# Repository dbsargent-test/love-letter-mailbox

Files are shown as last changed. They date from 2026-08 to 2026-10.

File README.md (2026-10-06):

# 📬 Love Letter Mailbox — DIY WiFi Messenger

A palm-sized, WiFi-connected mailbox that displays text messages and photos on a color screen. When a message arrives, a red flag rises and a chime plays. Inspired by [Love Letter Tech](https://lovelettertech.com), built from scratch with off-the-shelf components.

**Send a message from any phone → it appears on the mailbox. No app install required.**

Architecture Overview

---

## ✨ Current V1 Features

- 📱 **Send messages from any browser** — no app to install, works on any phone/tablet/computer
- 📸 **Photo support** — send photos that render on the V1 2.0" color IPS display
- 🚩 **Physical flag** — servo raises a red flag when a new message arrives
- 🔔 **Notification chime** — Qwiic buzzer plays a tone on message arrival
- 🌙 **Auto-dimming** — ambient light sensor dims the display at night
- 🔘 **Physical button** — mark messages as read, scroll through message history
- 💗 **Read heart receipts** — sent messages show when the recipient has read them
- 🔄 **Over-the-air updates** — push firmware updates remotely, no physical access needed
- 🔋 **Battery backup** — LiPo battery keeps the device running through power blips
- 📡 **Dual-band WiFi 6** — works on 2.4GHz AND 5GHz networks (no band-steering headaches)
- ☁️ **Azure-hosted backend** — reliable, free-tier, Microsoft infrastructure
- 🔒 **Encrypted** — all communication over HTTPS

## ✨ Planned V2 Features

V2 keeps the same Azure/web/ESP32 foundation and upgrades the physical mailbox:

- 🖼️ **Larger portrait display** — Adafruit 2.8" TFT with capacitive touch, EYESPI, and microSD
- 💾 **SD-backed media cache** — downloaded pictures and audio live on the TFT microSD card, not ESP32 flash
- 🎵 **Real audio playback** — ESP32-managed audio over I2S to a MAX98357A amplifier and enclosed speaker
- 💗 **Translucent glowing heart** — 3D-printed translucent heart insert lit by a NeoPixel Jewel
- 👆 **Heart-back touch input** — copper foil electrode and MPR121 capacitive touch sensing
- 💓 **Haptic heartbeat** — DRV2605L haptic controller and vibration motor
- 🧲 **Flag-state sensing** — Hall-effect sensor and magnet/reed-switch fallback
- 🔋 **Larger battery** — 2200mAh cylindrical LiIon cell, requiring a redesigned tray
- 🧰 **Serviceable internal layout** — new floor/tray for ESP32 bottom headers, microSD access, speaker chamber, haptics, and wiring

Full V2 planning is tracked in [docs/v2-build-plan.md](docs/v2-build-plan.md).

---

## 💰 V1 Cost Comparison

| | Love Letter Tech (Commercial) | This Project (DIY) |
|---|---|---|
| **Price** | $129 | **~$92** |
| **Dual-band WiFi** | ❌ (2.4GHz only) | ✅ WiFi 6 dual-band |
| **Battery backup** | ❌ | ✅ 850mAh LiPo |
| **Auto-dimming** | ❌ | ✅ Ambient light sensor |
| **Notification sound** | ❌ | ✅ Qwiic buzzer |
| **Physical button** | ❌ | ✅ Read/scroll |
| **OTA updates** | Unknown | ✅ Remote firmware updates |
| **Open source** | ❌ | ✅ Fully open |
| **Requires app install** | ✅ iOS/Android app | ❌ Any browser works |

---

## 💰 V2 Cost / Capability Snapshot

V2 is no longer optimized only for lowest cost; it is optimized for richer
interaction and OTA-manageable media.

| Area | V1 | V2 plan |
|---|---|---|
| Display | 2.0" ST7789 | 2.8" Adafruit #2090 TFT with capacitive touch and microSD |
| Notification sound | Qwiic buzzer tones | WAV/audio files from microSD through MAX98357A + speaker |
| Heart interaction | Read-heart receipt in web/app flow | Physical glowing/touch/haptic heart |
| Media storage | ESP32 RAM/cache + backend blobs | ESP32-managed microSD cache for downloaded images/audio |
| Battery | 850mAh flat LiPo | 2200mAh cylindrical LiIon |
| Enclosure | V1 tray and display fit | New tray required for bottom headers, battery, heart, speaker, and SD access |
| Incremental V2 purchases | — | Adafruit electronics order + Amazon microSD cards placed |

---

## 🛒 V1 Bill of Materials

| Part | Source | Product | Price |
|---|---|---|---|
| ESP32-C5 Thing Plus (×2) | SparkFun | [Thing Plus ESP32-C5](https://www.sparkfun.com/sparkfun-thing-plus-esp32-c5.html) | $24.95 ea |
| 2.0" TFT Display (2-pack) | Amazon | [XIITIA 2.0" ST7789 240×320 IPS](https://www.amazon.com/dp/B0DFWLD38D) | ~$12 |
| LiPo Battery 850mAh | SparkFun | [Lithium Ion Battery 850mAh](https://www.sparkfun.com/lithium-ion-battery-850mah.html) | $13.61 |
| Ambient Light Sensor | SparkFun | [VEML6030 Qwiic](https://www.sparkfun.com/sparkfun-ambient-light-sensor-veml6030-qwiic.html) | ~$6 |
| Buzzer | SparkFun | [Qwiic Buzzer](https://www.sparkfun.com/sparkfun-qwiic-buzzer.html) | ~$7 |
| Button | SparkFun | [Qwiic Button Red LED](https://www.sparkfun.com/products/15932) | ~$5 |
| Qwiic Cables 200mm (×3) | SparkFun | [Flexible Qwiic Cable 200mm](https://www.sparkfun.com/flexible-qwiic-cable-200mm.html) | $1.95 ea |
| SG90 Micro Servo | On hand | — | $0 |
| 3D Printed Enclosure | Self | STL files in `/enclosure` | ~$1 |
| **Total** | | | **~$92** |

> **Note:** BOM builds TWO complete mailboxes (one for you, one for recipient). Per-unit cost is ~$46.
> V2 uses a different expansion BOM; see [docs/v2-build-plan.md](docs/v2-build-plan.md).

---

## 🛒 V2 Bill of Materials

### Reused / Already In Stock

| Part | Purpose |
|---|---|
| SparkFun Thing Plus ESP32-C5 | Main controller, Wi-Fi, OTA, Qwiic, LiPo charging |
| 18-pin EYESPI FPC cable | Display cabling |
| EYESPI breakout / host wiring path | Prototyping and signal breakout |
| SparkFun Qwiic Button with LED | Fallback / alternate physical control |
| SparkFun VEML6030 ambient light sensor | Auto-dim / ambient light input |
| SG90 micro servo | Mailbox flag actuation |
| Qwiic cables | I2C daisy-chain wiring |

### Ordered for V2

| Part | Source / ID | Purpose |
|---|---|---|
| 2.8" TFT LCD with capacitive touch, EYESPI, and microSD | Adafruit #2090 | Larger display and media storage |
| MAX98357A I2S 3W Class-D mono amplifier | Adafruit #3006 | ESP32-managed audio playback |
| Mono enclosed speaker, 3W 4Ω | Adafruit #3351 | Audio output |
| DRV5032 digital magnetic Hall-effect sensor | Adafruit / ScoutMakes #6051 | Flag position sensing |
| Magnetic contact switch | Adafruit #375 | Magnet source / fallback contact sensor |
| 2200mAh cylindrical LiIon battery | Adafruit #1781 | Larger V2 power reserve |
| NeoPixel Jewel | Adafruit #2226 | Translucent heart glow |
| MPR121 capacitive touch sensor | Adafruit #4830 | Heart touch / heart-back input |
| Copper foil tape | Adafruit #1127 | Touch electrode |
| DRV2605L haptic motor controller | Adafruit #2305 | Heartbeat vibration effects |
| Vibrating mini motor disc | Adafruit #1201 | Haptic output |
| Half-size breadboard + jumper bundle | Adafruit #3314 | ESP32 fanout and shared power/ground rows |
| Lexar E-Series 32GB microSDHC UHS-I cards, 3-pack | Amazon | Media cache for downloaded pictures and audio |

### V2 Items Still Pending

| Item | Depends on |
|---|---|
| Speaker gasket, grille, and acoustic chamber | Final speaker location and vent geometry |
| M2/M2.5 screws, heat-set inserts, or self-tapping screws | Final display, speaker, sensor, and tray mounts |
| Optional separate microSD breakout | Only if the #2090 TFT microSD slot is not serviceable |

---

## 🏗️ V1 System Architecture

```
┌─────────────────────┐         ┌──────────────────────┐
│   Any Phone/Browser │         │    Azure Cloud       │
│                     │         │                      │
│  ┌───────────────┐  │  HTTPS  │  ┌────────────────┐  │
│  │ Messaging     │──┼────────►│  │ Static Web App │  │
│  │ Web Page      │  │         │  │ + Azure Func.  │  │
│  └───────────────┘  │         │  └───────┬────────┘  │
└─────────────────────┘         │          │           │
                                │  ┌───────▼────────┐  │
                                │  │ Table Storage   │  │
                                │  │ (messages)      │  │
                                │  └───────┬────────┘  │
                                │          │           │
                                │  ┌───────▼────────┐  │
                                │  │ Blob Storage    │  │
                                │  │ (photos + OTA)  │  │
                                │  └────────────────┘  │
                                └──────────┬───────────┘
                                           │ HTTPS poll
                                           │ every 5s
                                ┌──────────▼───────────┐
                                │   ESP32-C5 Mailbox   │
                                │                      │
                                │  ┌────────────────┐  │
                                │  │ V1 2.0" TFT    │  │
                                │  │ (text + photos)│  │
                                │  ├────────────────┤  │
                                │  │ Servo (flag)   │  │
                                │  ├────────────────┤  │
                                │  │ Buzzer (chime) │  │
                                │  ├────────────────┤  │
                                │  │ Light sensor   │  │
                                │  │ (auto-dim)     │  │
                                │  ├────────────────┤  │
                                │  │ Button (read/  │  │
                                │  │ scroll)        │  │
                                │  ├────────────────┤  │
                                │  │ LiPo (backup)  │  │
                                │  └────────────────┘  │
                                └──────────────────────┘
```

---

## 🏗️ V2 Device Architecture

The cloud/backend remains the same. The physical device changes from a buzzer
and 2.0" display into an ESP32-managed media and interaction hub:

```
Azure Static Web App + Functions + Table/Blob Storage
        │
        │ HTTPS: messages, photos, firmware, media metadata
        ▼
SparkFun Thing Plus ESP32-C5
        │
        ├── SPI / EYESPI ── Adafruit #2090 2.8" TFT
        │                    └── microSD media cache
        │
        ├── I2S ─────────── MAX98357A amp ── enclosed speaker
        │
        ├── GPIO ────────── NeoPixel Jewel behind translucent heart
        │
        ├── I2C/Qwiic ───── VEML6030 light sensor
        │              ├── MPR121 capacitive touch sensor
        │              └── DRV2605L haptic controller ── vibration motor
        │
        ├── GPIO ────────── Hall sensor / magnetic contact path
        │
        ├── PWM ─────────── SG90 flag servo
        │
        └── Battery ─────── 2200mAh cylindrical LiIon
```

The V2 firmware must add microSD file management, audio playback, NeoPixel
effects, capacitive touch, haptic effects, and flag-state sensing before the
new enclosure is treated as final.

---

## 🚀 Quickstart

### V1: Build / Run the Current Device

#### 1. Deploy the Azure Backend
See [docs/azure-setup.md](docs/azure-setup.md) for step-by-step instructions.

#### 2. Flash the Firmware
See [docs/firmware-setup.md](docs/firmware-setup.md) for Arduino IDE setup and flashing.

#### 3. Wire the Hardware
See [docs/wiring.md](docs/wiring.md) for pin connections and Qwiic daisy-chain.

#### 4. Print the Enclosure
STL files in [`/enclosure`](enclosure/). Any FDM printer works.

#### 5. Connect and Send Messages
Open the messaging web page, type a message, hit send. Watch the flag rise. ❤️

### V2: Build Path

V2 is in hardware planning/prototyping, not a ready-to-print release. The next
steps are:

1. Validate the #2090 TFT and microSD from the ESP32-C5.
2. Validate SD-backed image and audio file read/write.
3. Validate MAX98357A I2S audio playback from microSD.
4. Validate NeoPixel glow through translucent print samples.
5. Validate MPR121 touch detection through the heart/copper stack.
6. Validate DRV2605L haptics and motor placement.
7. Validate Hall sensor and magnet alignment for flag position.
8. Redesign the floor/tray around bottom-header ESP32 clearance and #1781 battery placement.
9. Print a fit coupon before printing a full V2 enclosure.

---

## 📖 Documentation

| Guide | Description |
|---|---|
| [Architecture](docs/architecture.md) | System design, failure analysis, and design decisions |
| [Bill of Materials](docs/bom.md) | Complete parts list with purchase links |
| [V2 Build Plan](docs/v2-build-plan.md) | V2 hardware architecture, ordered BOM, media storage, and enclosure implications |
| [Wiring Guide](docs/wiring.md) | Pin connections + Qwiic daisy-chain diagram |
| [Azure Setup](docs/azure-setup.md) | Deploy the backend in 15 minutes |
| [Firmware Setup](docs/firmware-setup.md) | Arduino IDE configuration + flashing |
| [OTA Updates](docs/ota-updates.md) | Push firmware updates remotely |
| [Troubleshooting](docs/troubleshooting.md) | Common issues and fixes |
| [Project Journal](docs/project-journal.md) | Build log, scope tracker, budget, and session history |

---

## 🛡️ Design Philosophy

This project was designed with **failure resistance** as the top priority. Every component choice was made to minimize the chance of the device becoming a paperweight:

- **Dual-band WiFi 6** eliminates the #1 ESP32 failure mode (2.4GHz band-steering hell)
- **Simple HTTP polling** instead of persistent connections — nothing to disconnect
- **Azure Table Storage** — Microsoft's oldest, most durable storage service
- **No native app** — a static web page can't break from app store policy changes
- **OTA updates** — fix bugs remotely without physical access
- **Battery backup** — survives power blips without losing state
- **Watchdog timer** — auto-reboots if firmware hangs

See [docs/architecture.md](docs/architecture.md) for the full failure analysis and design rationale.

---

## 📜 License

MIT License — build one, sell one, modify it, do whatever you want.

---

## 📊 Project Health

| Metric | Value |
|---|---|
| Current firmware source | **v1.2.10** |
| V1 physical build | **Complete / validated** |
| V2 hardware planning | **Captured; parts ordered; firmware/CAD not yet implemented** |
| Original features replicated | 8 of 10 (80%) |
| V1 features added beyond original | 9 |
| V1 scope creep ratio | 0.9x |
| V1 cost vs commercial ($129) | **$57/unit (56% cheaper)** |
| V2 primary blocker | **Validate new hardware stack before redesigning enclosure** |
| Monthly hosting cost | ~$0.02 |
| Architecture failure resistance score | **9.7 / 10** |

See [Project Journal](docs/project-journal.md) for full scope creep analysis and build log.

---

## 🌐 Live Backend

| Resource | URL |
|---|-----|
| Messaging Web App | https://zealous-dune-001e8941e.7.azurestaticapps.net |
| Azure Resource Group | `love-letter-mailbox` (West US 2) |

---

## 🙏 Acknowledgments

Inspired by [Love Letter Tech](https://lovelettertech.com) by Owen O'Brien. This is an independent open-source reimplementation — not affiliated with Love Letter Tech.

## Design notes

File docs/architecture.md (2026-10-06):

# Architecture & Design Decisions

## Lessons Learned

### 2026-09-17 — Use the policy-compatible ESP32-C5 toolchain helper

Windows Application Control blocks the temporary Python DLL extracted by
Espressif's bundled PyInstaller tools. Repeated Arduino CLI upload overrides
still invoked the blocked executable and failed before writing flash.

Use `scripts\esp32c5-toolchain.ps1` for both operations. Compilation routes the
partition generator through the installed Python runtime; upload consumes the
generated `flash_args` with `python -m esptool`. Do not weaken Application
Control or rediscover command-line overrides in later sessions.

### 2026-09-17 — SPI animations must not clear the full display per frame

The first floating-hearts screensaver cleared and redrew the entire 320×240
ST7789 every 120 ms. Because the display has no frame buffer or vertical-sync
swap, the cleared frame became visible over SPI and made the screen blink.

Animated elements now move in side lanes around a static central panel. Each
frame erases only the previous heart bounds and draws the new positions.
`tests\regression\test-landscape-screensaver-prefetch.ps1` rejects any return
of `display.fillScreen()` to the animated frame renderer.

### 2026-09-17 — Session revocation must be global and fail closed

Password changes previously revoked only the token used for the request, while
password resets revoked no active sessions. Revocation-table errors were also
treated as "not revoked," allowing stolen seven-day JWTs to survive account
recovery or a storage outage.

Every user now has a monotonic `sessionVersion` included in JWTs and checked
against Table Storage on every protected request. Password changes and resets
increment the version, invalidating all older sessions. Revocation lookup
returns "not revoked" only for an explicit entity-not-found response; other
storage failures return an authentication-service error rather than accepting
the token. Device credentials are accepted only through `x-device-key`, never
through query strings.

### 2026-09-16 — Native image dependencies must match the SWA runtime

The first image-normalization deployment returned HTTP 500 from the messages
function because Windows SWA CLI packaged only Sharp's Windows ARM64 native
binary, while Azure Static Web Apps runs Linux x64. The API source and package
lock were correct, which made the failure invisible to local tests.

Before every Windows-originated SWA deployment, run `npm --prefix web\api run
prepare:swa` to add Sharp and libvips for Linux x64 to the local deployment
tree. `tests\regression\test-swa-sharp-runtime.ps1` prevents removal of that
deployment gate.

### 2026-09-16 — Qwiic queue values are elapsed ages, not timestamps

The Qwiic Button maintains separate press and click queues. Their values are
milliseconds elapsed since each event, and unmatched press entries can remain
in the device queue. Pairing the oldest values without resynchronization caused
a quick tap to be measured as a 270,584 ms hold.

The firmware now discards implausible unmatched entries, computes hold duration
from paired ages, reconstructs the click time as `millis() - clickAge`, and
logs the selected action. The double-click window is 750 ms because USB traces
showed a normal double press at 707 ms. The regression guard is
`tests\regression\test-button-gesture-timing.ps1`.

## Overview

The Love Letter Mailbox is a WiFi-connected IoT device that receives text
messages and photos from a web interface and displays them on a color TFT
screen. The validated V1 hardware raises a servo-driven flag when a new message
arrives, plays a Qwiic buzzer notification chime, and uses a physical button to
mark messages as read. V2 planning is tracked in
[Mailbox V2 Build Plan](v2-build-plan.md) and adds a larger TFT, SD-backed media
cache, real audio playback, translucent glowing heart, capacitive heart-back
input, haptic feedback, and flag-state sensing.

## Design Principles

1. **Minimize failure modes** — every architectural choice prioritizes reliability over cleverness
2. **No persistent connections** — HTTP polling over MQTT/WebSockets to eliminate connection state management
3. **No native app** — a static web page works on any device without installation or app store approval
4. **Normalize once in the backend** — browser previews are optimized, but the
   API authoritatively rotates and scales every stored photo
5. **Vendor-portable** — the ESP32 code is just "fetch JSON from a URL"; swap backends by changing one URL

---

## Component Selection Rationale

### ESP32-C5 (over classic ESP32)

| Factor | ESP32 (classic) | ESP32-C5 |
|---|---|---|
| WiFi | 2.4GHz only | **Dual-band 2.4 + 5GHz WiFi 6** |
| RAM | 520KB SRAM | 384KB SRAM + **8MB PSRAM** |
| Flash | 4MB | **8MB** |
| Battery | External charging circuit needed | **Built-in LiPo charger + fuel gauge** |
| Power safety | Brownout-prone on WiFi TX | LiPo battery acts as capacitor |

**Decision:** The ESP32-C5 eliminates the two most common IoT project failures:
1. **2.4GHz WiFi incompatibility** with modern routers that use band steering
2. **Memory crashes** when decoding photos (8MB PSRAM vs 520KB SRAM)

The $19 premium ($25 vs $6) is justified by the elimination of these failure modes.

### Azure Static Web App + Table Storage (over Firebase, MQTT, Blynk)

Three architectures were evaluated:

#### Option A: Firebase Realtime DB + PWA
- **Pros:** Well-documented, free tier generous, real-time listeners
- **Cons:** Google dependency, Firebase SDK on ESP32 is heavy, vendor lock-in
- **Score:** 8.0/10

#### Option B: MQTT (HiveMQ) + Telegram Bot
- **Pros:** MQTT is resilient by design, Telegram is battle-tested
- **Cons:** Needs bridge server between Telegram and MQTT (single point of failure), more moving parts
- **Score:** 8.0/10

#### Option C: Azure Static Web App + Table Storage ✅ SELECTED
- **Pros:** Fewest moving parts, ESP32 just does HTTP GET, Table Storage is nearly indestructible (99.999999999% durability), $0.01/mo cost, no SDK needed
- **Cons:** Polling instead of push (5-second delay is acceptable for a mailbox)
- **Score:** 9.7/10

**Decision:** Option C wins on simplicity, cost, and failure resistance. The ESP32 code is just `HTTPClient.GET()` — no MQTT library, no Firebase SDK, no connection state to manage. If Azure ever changes, swapping to any JSON endpoint takes ~10 lines of code change.

### V1 2.0" ST7789 TFT (over 1.3", 1.69", 2.4")

| Display | Resolution | Photo Quality | Enclosure Fit |
|---|---|---|---|
| 1.3" | 240×240 | Too small for photos | Very compact |
| 1.69" | 240×280 | Recognizable but tight | Compact |
| **2.0"** | **240×320** | **Good — natural photo aspect ratio** | **Palm-sized mailbox** |
| 2.4" | 240×320 | Good | Enclosure gets bulky |

**V1 decision:** 2.0" was the validated V1 sweet spot. 240×320 matches standard
photo aspect ratios, avoiding letterboxing. Physically only ~5mm larger than
1.69" but noticeably better for photo viewing.

**V2 update:** V2 moves to Adafruit #2090, a 2.8" TFT with capacitive touch,
EYESPI, and microSD. The larger display and SD socket drive the V2 enclosure,
media-cache, and power-budget work in [v2-build-plan.md](v2-build-plan.md).

---

## Failure Analysis

### Risk Register

| # | Failure Mode | Pre-Mitigation Risk | Mitigation | Post-Mitigation Risk |
|---|---|---|---|---|
| 1 | 2.4GHz WiFi band-steering | HIGH | ESP32-C5 dual-band WiFi 6 | **ELIMINATED** |
| 2 | Cloud service changes/dies | MEDIUM | Azure Table Storage (oldest Azure service), no SDK lock-in, swap backend in 10 lines | **LOW** |
| 3 | WiFi reconnect failures | HIGH | WiFi 6 better connection management + hardware watchdog + exponential backoff | **LOW** |
| 4 | Power brownouts | MEDIUM | LiPo battery acts as UPS during voltage dips | **ELIMINATED** |
| 5 | TLS cert expiration | LOW | Azure-managed certs, Arduino core updates CA bundle | **VERY LOW** |
| 6 | Photo decode OOM crash | MEDIUM | 8MB PSRAM for decode buffer; fallback: pre-convert to RGB565 in browser | **ELIMINATED** |
| 7 | Web UI/app maintenance | MEDIUM | Static HTML/JS, no framework dependencies, no native app | **LOW** |
| 8 | WiFi provisioning confusion | HIGH | Captive portal + dual-band means no "split your SSID" instructions needed | **LOW** |

### Resilience Features

- **Hardware watchdog:** Auto-reboots ESP32 after 60 seconds of unresponsiveness
- **Exponential backoff:** WiFi reconnect attempts with increasing delays (1s, 2s, 4s, 8s... max 60s)
- **Dual OTA partitions:** Failed firmware update auto-rolls back to previous working version
- **Message persistence:** Azure Table Storage holds last 20 messages; ESP32 fetches unread on boot
- **Offline display:** Last message stays on screen even if WiFi drops
- **Battery fuel gauge:** Firmware can warn when battery is low (display icon)

---

## Data Flow

### Sending a Message

```
1. User opens web page on phone/computer
2. Types message and/or attaches photo
3. Browser creates an aspect-ratio-preserving preview within 216×160
4. JavaScript POSTs to Azure Function: POST /api/messages
5. Azure Function rotates the photo from metadata, strips metadata, converts it
   to baseline JPEG, and fits it inside 216×160 without cropping, stretching,
   enlarging, or changing portrait/landscape orientation
6. Azure Function writes to Table Storage:
   - PartitionKey: device ID
   - RowKey: timestamp
   - Text: message content
   - PhotoUrl: Blob Storage URL (if photo)
   - Read: false
7. Function returns 200 OK
```

### Receiving a Message

```
1. ESP32-C5 polls GET /api/messages?unread=true every 5 seconds
2. If unread messages exist:
   a. Raise servo flag
   b. V1: play Qwiic buzzer chime; V2: play SD-backed audio through I2S amp
   c. Display message text on TFT
   d. If photo: use one of two RAM cache slots or download from Blob Storage,
      decode, center, and render without changing its aspect ratio
3. When button pressed:
   a. Mark message as read: PATCH /api/messages/{id}
   b. Lower servo flag
   c. Show next unread message (if any) or return to idle screen
```

### OTA Firmware Update

```
1. On boot + every 15 minutes: GET /api/device/firmware
2. Compare server version string to local version
3. If server > local:
   a. Download .bin from Azure Blob Storage
   b. Write to OTA partition B
   c. Verify checksum
   d. Set boot partition to B
   e. Reboot
4. The new image is confirmed only after display and I2C peripherals initialize
5. If the pending image reboots before confirmation, the ESP32 bootloader can
   return to the previous OTA partition
```

---

## V1 Qwiic Daisy-Chain

V1 I2C peripherals connect via the Qwiic connector system — no soldering required:

```
ESP32-C5 Qwiic Port
    │
    ├── [200mm cable] ── VEML6030 Light Sensor
    │                         │
    │                    [200mm cable]
    │                         │
    │                    Qwiic Buzzer
    │                         │
    │                    [200mm cable]
    │                         │
    │                    Qwiic Button
    │
    └── [SPI wires] ── 2.0" ST7789 TFT Display
    │
    └── [signal wire] ── SG90 Servo
```

### I2C Addresses (no conflicts)
| Device | Address |
|---|---|
| VEML6030 | 0x48 |
| Qwiic Buzzer (ATtiny84) | 0x34 |
| Qwiic Button | 0x6F |
| MAX17048 Fuel Gauge (onboard) | 0x36 |

V2 adds MPR121 capacitive touch and DRV2605L haptic control on I2C. Their
addresses must be scanned before final wiring; if both use the same default
address, change the MPR121 address before integrating both boards.

---

## Azure Resource Summary

| Resource | Tier | Monthly Cost | Purpose |
|---|---|---|---|
| Static Web App | Free | $0 | Hosts messaging web page + API functions |
| Storage Account (Table) | Standard | ~$0.01 | Message storage |
| Storage Account (Blob) | Standard | ~$0.01 | Photo storage + OTA firmware binaries |
| **Total** | | **~$0.02/mo** | |

All resources fit within the Azure free tier and/or the $200/mo Visual Studio Enterprise credit.

---

## Future Enhancements

- [x] Read receipts (sender sees when message was viewed)
- [ ] V2 SD-backed audio playback (MAX98357A + speaker)
- [ ] V2 heart-back interaction (capacitive touch + haptics)
- [ ] Emoji rendering (custom font with emoji glyphs)
- [ ] Weather display on idle screen
- [ ] Multiple device pairing (family group messaging)
- [ ] E-ink display option for ultra-low power
- [ ] Custom notification melodies
- [ ] Message reactions / heart-back replies

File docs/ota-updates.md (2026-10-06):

# OTA (Over-the-Air) Firmware Updates

## Overview

The mailbox firmware includes built-in OTA update capability. Once the initial firmware is flashed via USB, all subsequent updates can be pushed remotely — no physical access to the device required.

This is critical for a device deployed at someone else's house.

This page covers firmware OTA. V2 also needs an OTA media-cache workflow for
downloaded pictures and audio files stored on the #2090 TFT microSD card; that
media workflow is planned separately in [Mailbox V2 Build Plan](v2-build-plan.md).

---

## How It Works

```
1. You compile new firmware → export as .bin
2. Upload .bin to Azure Blob Storage
3. Update version number in Azure Table Storage
4. ESP32-C5 checks for updates on boot + every 15 minutes
5. If new version available → downloads .bin → installs → reboots
6. If new firmware crashes → auto-rollback to previous version
```

---

## Architecture

### ESP32-C5 Flash Partition Layout

The ESP32-C5 has 8MB flash, partitioned as:

| Partition | Size | Purpose |
|---|---|---|
| bootloader | 32KB | First-stage bootloader |
| partition table | 4KB | Partition layout |
| nvs | 20KB | WiFi credentials + settings |
| ota_0 | ~3.5MB | Firmware slot A (active) |
| ota_1 | ~3.5MB | Firmware slot B (OTA target) |
| ota_data | 8KB | Tracks which slot is active |
| spiffs/littlefs | ~512KB | Fonts, splash screens, cached data |

### Update Flow

```
Current firmware running from ota_0
    │
    ├── GET /api/device/firmware
    │   Response: { "version": "1.2.5", "url": "https://...blob.../firmware-1.2.5.bin" }
    │
    ├── Compare: local "1.2.4" < server "1.2.5" → update needed
    │
    ├── Download firmware-1.2.5.bin to ota_1 partition
    │
    ├── Verify checksum (SHA-256)
    │
    ├── Set ota_data to boot from ota_1
    │
    └── Reboot
        │
        ├── New firmware boots from ota_1
        │   ├── Initializes the display and required I2C peripherals
        │   ├── If initialization passes → mark ota_1 as confirmed
        │   └── If it reboots before confirmation → bootloader can roll back
        │
        └── Device now running v1.2.5
```

---

## Step-by-Step: Pushing an Update

### 1. Compile New Firmware

Use the policy-compatible repository helper from the repo root. The OTA build
must use the Minimal SPIFFS partition and should redact local source paths from
the binary:

```powershell
$build = "C:\Temp\mailbox-firmware-build-vNEXT"
$map = "-ffile-prefix-map=C:\Users\dosarge=."
$props = @(
  "compiler.c.extra_flags=$map",
  "compiler.cpp.extra_flags=$map",
  "compiler.S.extra_flags=$map"
)

.\scripts\esp32c5-toolchain.ps1 `
  -Action Compile `
  -SketchDirectory .\firmware\mailbox_firmware `
  -BuildPath $build `
  -Fqbn "esp32:esp32:sparkfun_esp32c5_thing_plus:PartitionScheme=min_spiffs" `
  -ExtraBuildProperty $props
```

The OTA application binary is:

```text
$build\mailbox_firmware.ino.bin
```

Do **not** upload the merged 8 MB image for OTA.

### 2. Upload to Azure Blob Storage

```bash
# Using Azure CLI
az storage blob upload \
  --account-name <your-storage-account> \
  --container-name firmware \
  --name firmware-<version>.bin \
  --file <build-path>/mailbox_firmware.ino.bin \
  --overwrite
```

Or upload via the Azure Portal: Storage Account → Containers → firmware → Upload.

### 3. Update Version Metadata

The device endpoint is controlled by Static Web App app settings, not by a
firmware metadata table. The critical hash is the **ESP image validation hash**,
not the raw file SHA-256.

Get the correct validation hash with:

```powershell
python -m esptool image-info "<build-path>\mailbox_firmware.ino.bin"
```

Use the `Validation hash: ... (valid)` value from the output. Do **not** use
`Get-FileHash` for `FIRMWARE_SHA256`; the firmware verifies OTA with
`esp_partition_get_sha256(updatePartition)`, which matches the ESP image
validation hash, not the raw `.bin` file hash.

Update the Static Web App metadata:

```powershell
az staticwebapp appsettings set `
  --name love-letter-app `
  --resource-group love-letter-mailbox `
  --setting-names `
    FIRMWARE_RELEASE_ENABLED=true `
    FIRMWARE_VERSION=<version> `
    FIRMWARE_BLOB_NAME=firmware-<version>.bin `
    FIRMWARE_SHA256=<ESP image validation hash> `
    FIRMWARE_RELEASE_NOTES="<short release note>"
```

### 4. Wait

The ESP32 checks for updates:
- On every boot
- Every 15 minutes while running in normal release builds
- Every 2 minutes in temporary test builds such as v1.2.7+

Within 15 minutes, the device will check for an update. Reboot the device to
trigger an earlier check after Wi-Fi reconnects.

---

## Safety Features

### Automatic Rollback
The firmware confirms a pending OTA image only after the display and required
I2C peripherals initialize. If the image reboots before confirmation, the
ESP32 bootloader can return to the previous OTA partition. Wi-Fi connectivity
is retried independently and is not currently part of the confirmation gate.

### Checksum Verification
Before installing, the firmware verifies the downloaded OTA partition with
`esp_partition_get_sha256(updatePartition)` against `FIRMWARE_SHA256` from the
version metadata. That value must be the ESP image validation hash reported by
`python -m esptool image-info`, not the raw `.bin` file SHA-256. If the wrong
hash type is published, the mailbox shows `OTA verification failed` and remains
on the previous firmware version.

### Incremental Updates Only
The ESP32 only updates if the server version is **newer** than the local version. This prevents update loops and unnecessary reboots.

---

## Security Considerations

- **HTTPS only:** Firmware is downloaded over HTTPS from Azure Blob Storage
- **SAS tokens:** Use Azure Shared Access Signatures with expiration to secure the firmware blob
- **No unsigned code:** Consider adding firmware signing in v2 (verify the binary was built by you before installing)
- **Version rollback protection:** The firmware won't "downgrade" to an older version unless forced via USB

---

## Monitoring

The firmware logs OTA activity to the serial console:
```
[OTA] Checking for updates...
[OTA] Current version: 1.1.0
[OTA] Server version: 1.2.0
[OTA] Update available! Downloading...
[OTA] Download complete. Size: 1,234,567 bytes
[OTA] SHA-256 verified.
[OTA] Installing to partition ota_1...
[OTA] Install complete. Rebooting...
```

If the device is remote and you can't access serial, the firmware posts heartbeat
and OTA lifecycle telemetry to `POST /api/device/status`; the API stores the
latest snapshot in `deviceStatus` and event history in `deviceEvents`.

---

## Emergency Recovery

If OTA fails AND the rollback fails (extremely unlikely with dual partitions):

1. Physical access required
2. Connect USB-C cable
3. Hold BOOT button + press RESET to enter bootloader mode
4. Flash firmware via Arduino IDE as usual
5. This is the only scenario where physical access is needed after initial deployment

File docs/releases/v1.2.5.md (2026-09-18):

# Firmware v1.2.5

Build date: 2026-09-17

## Highlights

- Landscape 320x240 display layout.
- Floating-hearts screensaver after two minutes of inactivity.
- Photo prefetch before notification and first reveal.
- Two-slot LRU photo cache with a 512 KB per-image limit.
- Single-press next, double-press back, and one-second hold to mark read.
- Authenticated OTA polling every 15 minutes.

## Build

| Property | Value |
|---|---|
| Board | SparkFun ESP32-C5 Thing Plus |
| FQBN | `esp32:esp32:sparkfun_esp32c5_thing_plus` |
| Partition | Minimal SPIFFS (`min_spiffs`) |
| Espressif Arduino core | 3.3.11 |
| Binary size | 1,359,280 bytes |
| Program storage | 1,359,133 bytes (69%) |
| Dynamic memory | 71,564 bytes (21%) |
| SHA-256 | `613b6bc3219ce74f4dc39a4564869f9929fb80bd827f8d2fd5d3a1d003bb0e51` |

The release asset is compiled without `EMBED_PROVISIONING_SECRETS`. It contains
no Wi-Fi password, device key, deployment URL, or private build path. Existing
devices load their configuration from NVS.

## Validation

- Arduino compilation succeeded.
- ESP image type detected as ESP32-C5 with 8 MB flash.
- Image checksum and validation hash passed.
- API tests and firmware regression guards passed.

The binary has not yet been installed on the physical mailbox or validated
through an OTA upgrade from v1.2.4.

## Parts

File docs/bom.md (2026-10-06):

# V1 Bill of Materials

> **This BOM builds TWO complete mailboxes** (one for you, one for your recipient).
> Per-unit cost: ~$46
> V2 expansion parts are tracked separately in
> [Mailbox V2 Build Plan](v2-build-plan.md).

## Core Components

| Part | Qty | Source | Product | Unit Price | Total | Notes |
|---|-----|---|---|---|---|---|
| ESP32-C5 Dev Board | 2 | SparkFun | [Thing Plus ESP32-C5](https://www.sparkfun.com/sparkfun-thing-plus-esp32-c5.html) | $24.95 | $49.90 | Dual-band WiFi 6, 8MB PSRAM, 8MB Flash, built-in LiPo charger + fuel gauge |
| 2.0" TFT Display | 2 | Amazon | [XIITIA ST7789 240×320 IPS (2-pack)](https://www.amazon.com/dp/B0DFWLD38D) | $12.00 (pack) | $12.00 | ST7789 driver, SPI, 3.3V, IPS wide viewing angle |
| Micro Servo | 2 | On hand | SG90 9g Micro Servo | — | $0 | Any SG90 clone works. Raises/lowers the flag |
| LiPo Battery | 2 | SparkFun | [Lithium Ion Battery 850mAh](https://www.sparkfun.com/lithium-ion-battery-850mah.html) | $13.61 | $27.22 | JST-PH connector, plugs directly into C5 Thing Plus |

## Qwiic Peripherals

| Part | Qty | Source | Product | Unit Price | Total | Notes |
|---|-----|---|---|---|---|---|
| Ambient Light Sensor | 1+ | SparkFun | [VEML6030 Qwiic](https://www.sparkfun.com/sparkfun-ambient-light-sensor-veml6030-qwiic.html) | ~$6.00 | $6.00 | Auto-dim display at night. I2C addr 0x48 |
| Buzzer | 1+ | SparkFun | [Qwiic Buzzer](https://www.sparkfun.com/sparkfun-qwiic-buzzer.html) | ~$7.00 | $7.00 | Notification chime on message arrival |
| Button | 1+ | SparkFun | [Qwiic Button Red LED](https://www.sparkfun.com/products/15932) | ~$5.00 | $5.00 | Mark as read, scroll messages |
| Qwiic Cable 200mm | 3+ | SparkFun | [Flexible Qwiic Cable 200mm](https://www.sparkfun.com/flexible-qwiic-cable-200mm.html) | $1.95 | $5.85 | One per link in the daisy chain |

## Enclosure & Misc

| Part | Qty | Source | Product | Unit Price | Total | Notes |
|---|-----|---|---|---|---|---|
| 3D Printed Enclosure | 2 | Self | STL files in `/enclosure` | ~$0.50 | $1.00 | PLA filament, any FDM printer |
| Dupont Wires | 1 set | On hand | Assorted M-F, F-F | — | $0 | For SPI display wiring |
| USB-C Cable | 2 | On hand | Any USB-C cable | — | $0 | Power + initial firmware flash |
| Red craft foam/paper | 2 | On hand | For the flag | — | $0 | Glue to servo horn |

## Cost Summary

| Category | Cost |
|---|---|
| Boards (×2) | $49.90 |
| Displays (2-pack) | $12.00 |
| Batteries (×2) | $27.22 |
| Qwiic peripherals | $23.85 |
| Enclosure + misc | ~$1.00 |
| **Grand Total** | **~$113.97** |
| **Per mailbox** | **~$57** |

## Monthly Operating Cost

| Resource | Cost |
|---|---|
| Azure Static Web App (Free tier) | $0 |
| Azure Table Storage | ~$0.01 |
| Azure Blob Storage (photos + OTA) | ~$0.01 |
| **Total** | **~$0.02/mo** |

Covered by Azure Visual Studio Enterprise credit ($200/mo).

---

## Alternative Display Options

If the XIITIA 2-pack is unavailable, these are compatible replacements (same ST7789, same libraries):

| Product | Source | Price |
|---|---|---|
| [Adafruit 2.0" 320×240 IPS TFT (Product #4311)](https://www.adafruit.com/product/4311) | Adafruit | $19.95 |
| [NULLLAB 2.0" ST7789 240×320](https://www.amazon.com/NULLLAB-Interface-Compatible-Embedded-Projects/dp/B0GVF8R5ZL) | Amazon | ~$7 |
| [AITRIP 2.0" ST7789 240×320](https://www.amazon.com/AITRIP-2-0inch-Raspberry-Electronics-Projects/dp/B0H8RNZY9M) | Amazon | ~$7 |

## Alternative Battery Options

If the SparkFun 850mAh is unavailable:
- Any single-cell 3.7V LiPo with a **2-pin JST-PH** connector will work
- Adafruit and Amazon carry many options in the 400-1200mAh range
- Larger capacity = longer backup time, but physically bigger

---

## V2 Hardware Expansion

V2 planning is tracked in [Mailbox V2 Build Plan](v2-build-plan.md). The V2
parts list adds a larger 2.8" TFT with microSD, ESP32-managed audio playback,
translucent heart lighting, capacitive heart input, haptic feedback, flag-state
sensing, and a larger cylindrical battery.

The V2 bill of materials is not a drop-in replacement for this V1 BOM. It
requires a redesigned internal tray because the real ESP32-C5 build has
bottom-soldered headers and the selected 2200mAh battery is cylindrical rather
than a flat pouch cell.

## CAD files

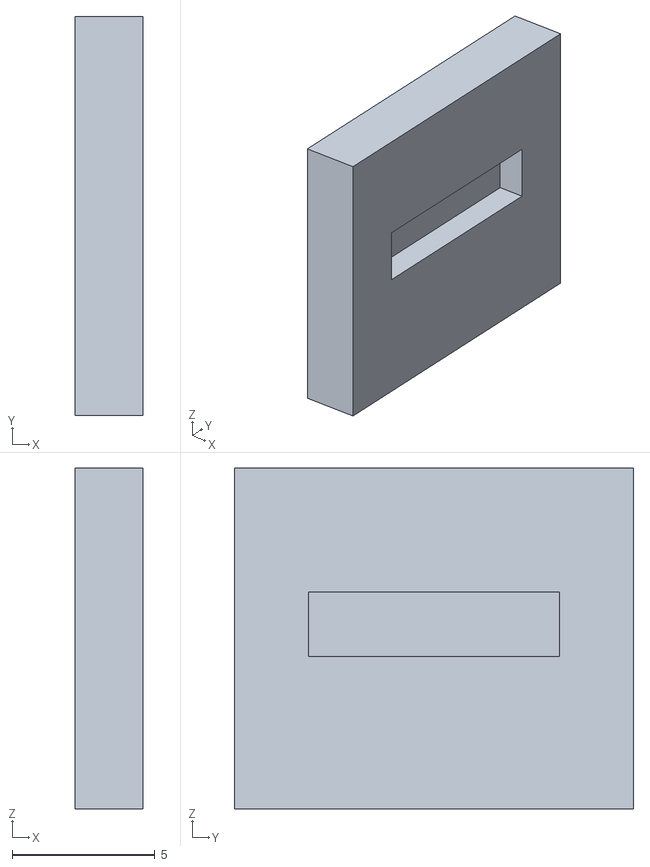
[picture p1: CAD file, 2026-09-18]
enclosure/stl/mailbox_v2_coupon_snap_housing.stl
2.40 x 14.0 x 11.9

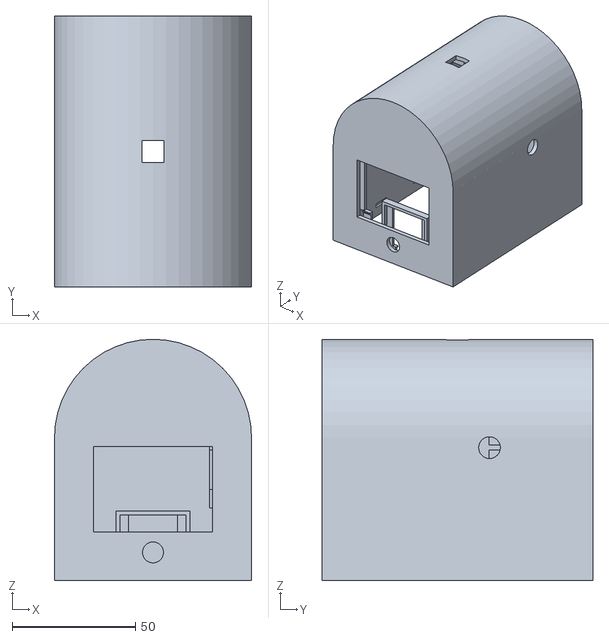
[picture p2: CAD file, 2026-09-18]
enclosure/stl/mailbox_v2_housing.stl
80.0 x 110.0 x 98.0

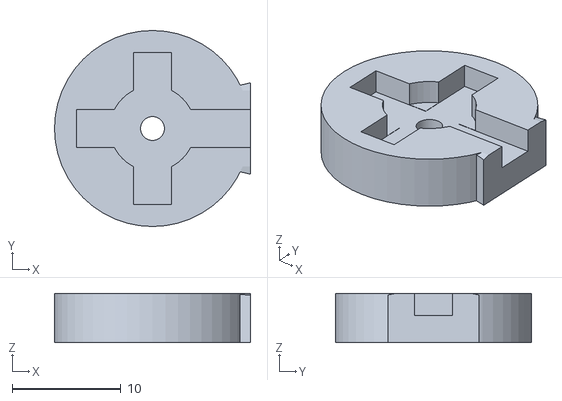
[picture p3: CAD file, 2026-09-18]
enclosure/stl/mailbox_v2_coupon_sg90_horn.stl
18.0 x 18.0 x 4.50

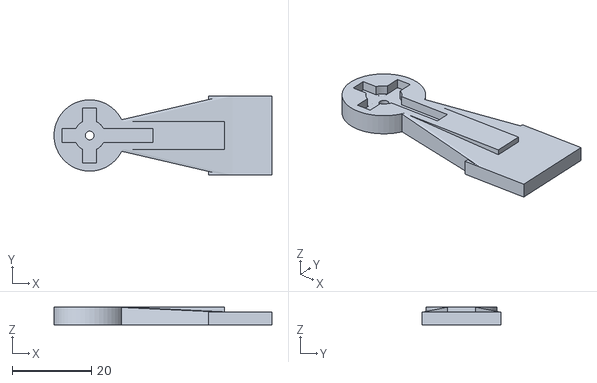
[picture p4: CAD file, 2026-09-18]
enclosure/stl/mailbox_v2_servo_flag.stl
55.0 x 20.0 x 4.50

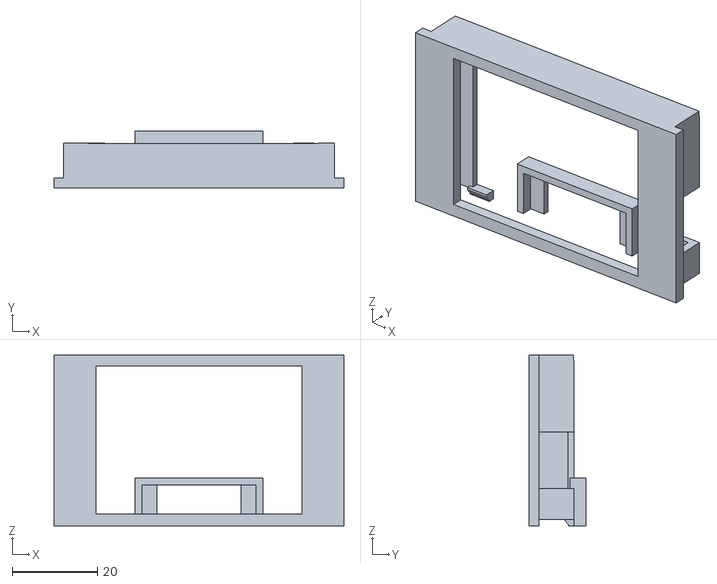
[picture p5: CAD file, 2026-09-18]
enclosure/stl/mailbox_v2_coupon_tft_front.stl
68.0 x 13.4 x 40.0

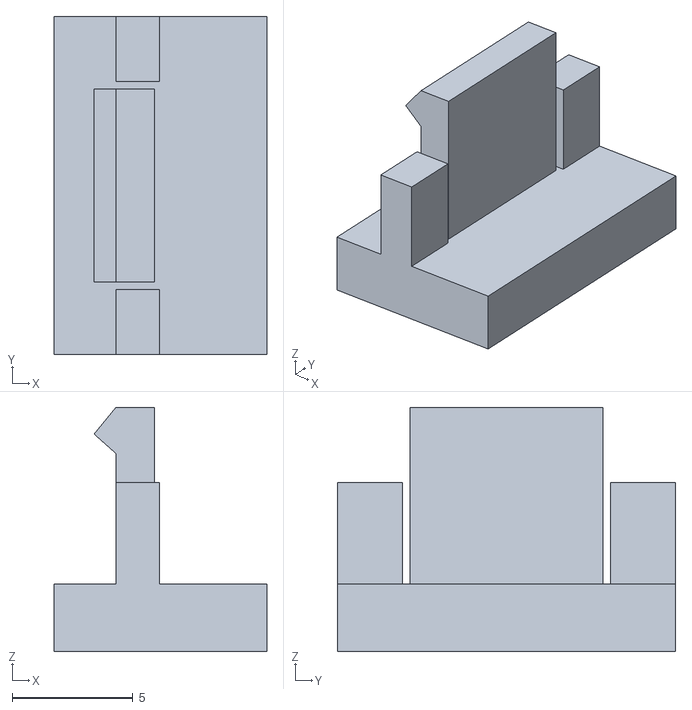
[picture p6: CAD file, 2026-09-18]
enclosure/stl/mailbox_v2_coupon_snap_floor.stl
8.80 x 14.0 x 10.1

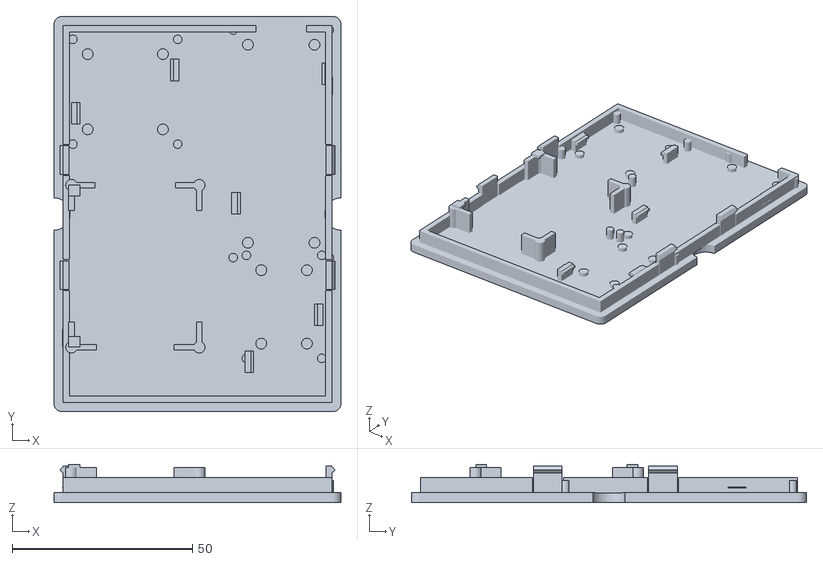
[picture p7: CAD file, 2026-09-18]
enclosure/stl/mailbox_v2_floor_tray.stl
79.7 x 109.7 x 10.6

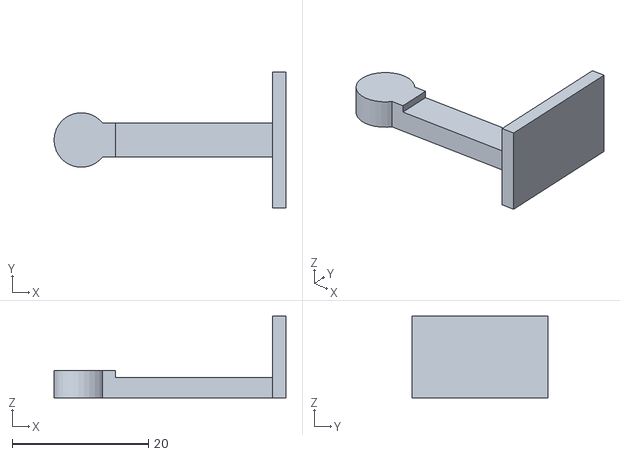
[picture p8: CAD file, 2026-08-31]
enclosure/stl/mailbox_flag.stl
34.0 x 20.0 x 12.0

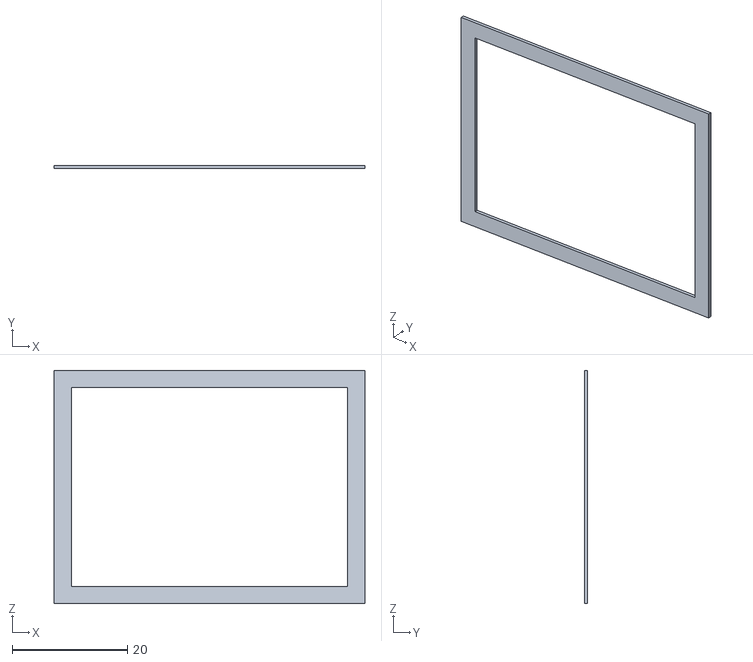
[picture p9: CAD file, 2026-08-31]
enclosure/stl/mailbox_door_frame.stl
54.0 x 0.6 x 40.5

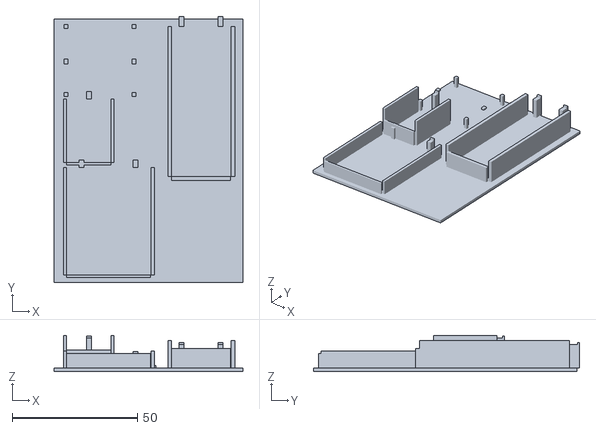
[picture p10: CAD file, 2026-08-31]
enclosure/stl/mailbox_tray.stl
75.4 x 106.4 x 14.5

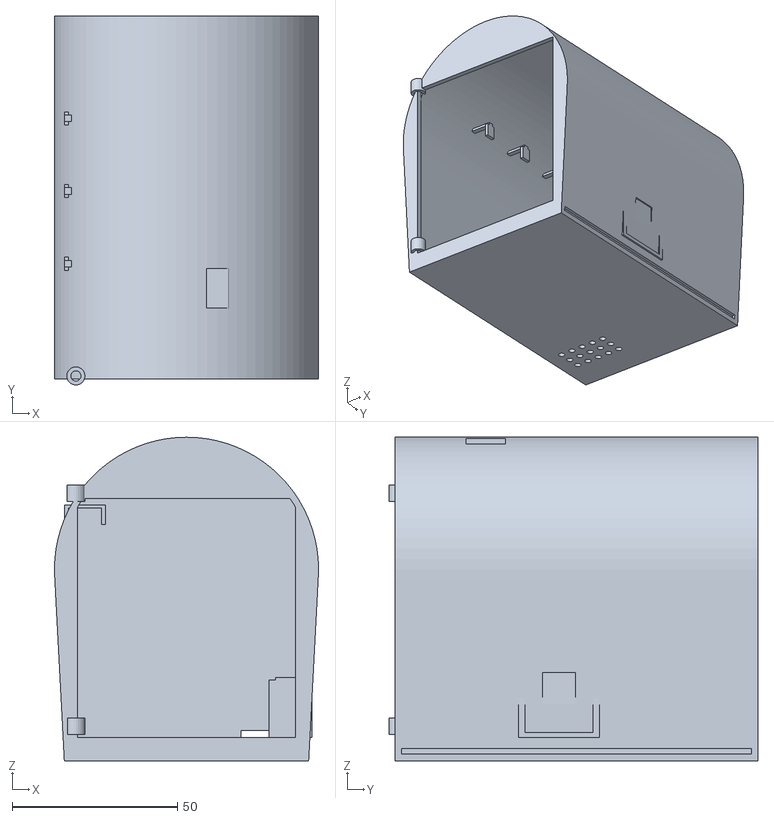
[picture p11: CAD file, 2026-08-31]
enclosure/stl/mailbox_body.stl
80.0 x 111.8 x 98.0

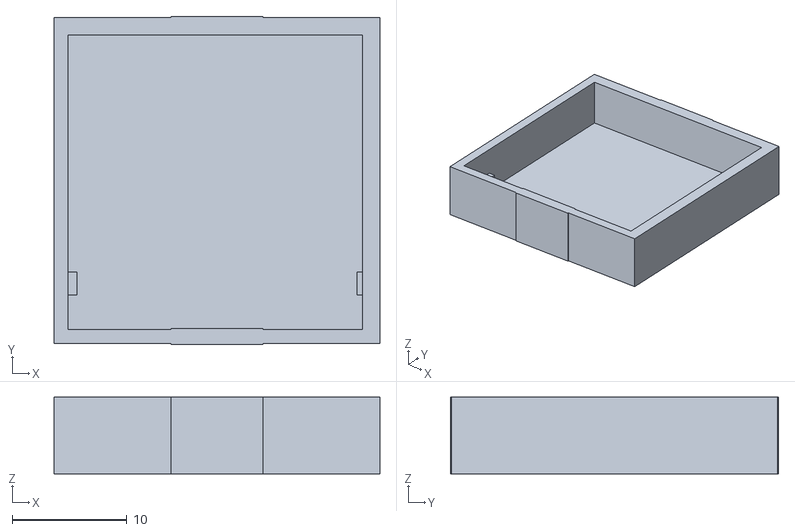
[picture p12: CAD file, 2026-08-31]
enclosure/stl/mailbox_sensor_bracket.stl
28.4 x 28.6 x 6.70

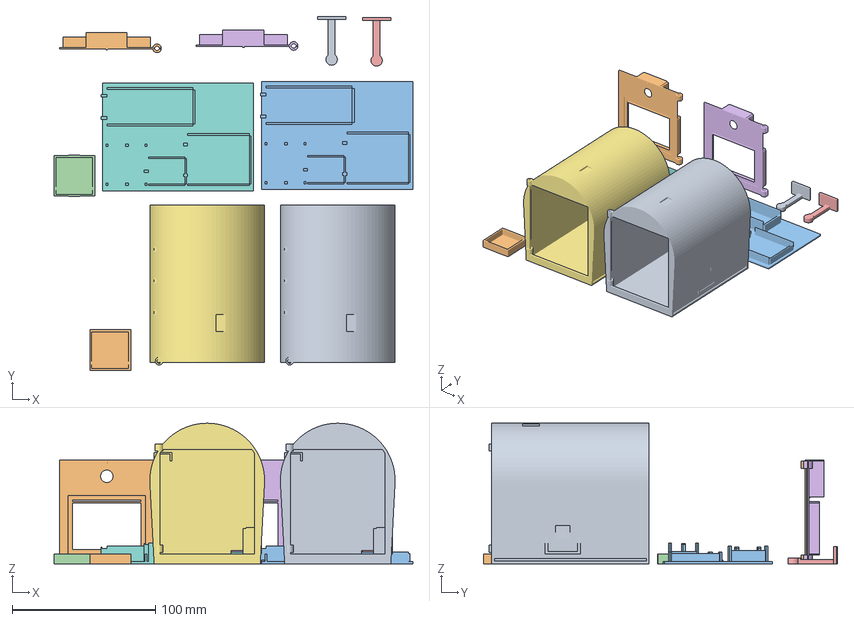
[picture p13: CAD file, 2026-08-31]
enclosure/stl/mailbox V1.3mf
250.1 x 246.8 x 98.0 mm
mailbox_body.stl x 2
mailbox_door.stl x 2
mailbox_tray.stl x 2
mailbox_sensor_bracket.stl x 2
mailbox_flag.stl x 2

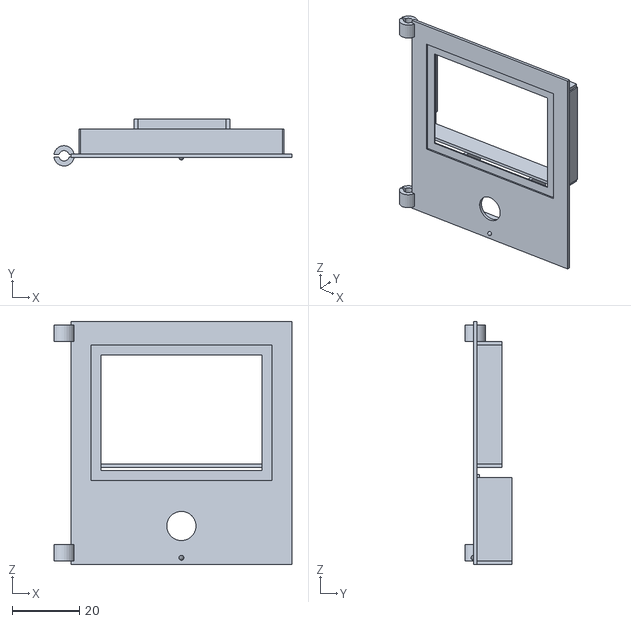
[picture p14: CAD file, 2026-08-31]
enclosure/stl/mailbox_door.stl
71.0 x 14.1 x 72.5

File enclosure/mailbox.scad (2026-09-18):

// Love Letter Mailbox v2 - three-part, bottom-serviceable enclosure.

render_part = "assembled";
$fn = 48;
eps = 0.05;

// Envelope
mailbox_length = 110;
mailbox_width = 80;
straight_wall_h = 58;
roof_radius = 40;
wall = 2.4;

// Measured electronics
esp_length = 60;
esp_width = 23.5;
esp_height = 15.5;
usb_width = 9;
usb_height = 3.2;

tft_pcb_width = 59.2;
tft_pcb_height = 35.5;
tft_depth = 6;
tft_screen_width = 48;
tft_screen_height = 34.5;

eyespi_length = 25.4;
eyespi_width = 17.7;
eyespi_height = 12;

servo_body_y = 22.5;
servo_body_x = 12;
servo_body_z = 28;
servo_total_z = 30.8;
servo_tab_span = 32.3;
servo_pivot_above_bottom = 16;

qbtn_pcb_x = 26;
qbtn_pcb_z = 25;
qbtn_shaft_d = 8.1;
qbtn_total_depth = 9.5;

sensor_pcb_x = 25.4;
sensor_pcb_y = 25.4;
sensor_total_z = 4.7;

buzzer_x = 25.9;
buzzer_y = 25.9;
buzzer_z = 4.2;

battery_x = 35.5;
battery_y = 45;
battery_z = 5.8;

// Fits
rigid_clearance = 0.4;
tft_pocket_x = 60.0;
tft_pocket_z = 36.3;
tft_pocket_depth = 6.8;
sensor_pocket_x = 26.2;
sensor_pocket_y = 26.2;
sensor_pocket_z = 5.2;

// Floor and snap system
floor_t = 2.8;
floor_edge_gap = 0.15;
tongue_clearance = 0.3;
tongue_t = 1.8;
tongue_h = 4.2;
snap_h = 7.4;
snap_w = 8;
snap_y_positions = [38, 70];

// Layout datums
tft_center_z = 37.1;
button_center_z = 11.5;
servo_pivot_y = 68;
servo_pivot_z = 54;
sensor_center_y = mailbox_length / 2;

floor_esp_x = 51.5;
floor_esp_y = 44.5;
floor_battery_x = 5;
floor_battery_y = 18;
floor_eyespi_x = 55.2;
floor_eyespi_y = 16.5;
floor_buzzer_x = 7;
floor_buzzer_y = 76;

// Flag and typical SG90 stock horn assumptions
flag_t = 4.5;
flag_arm_length = 34;
flag_arm_w = 7;
flag_plate_x = 16;
flag_plate_y = 20;
horn_recess_depth = 2.0;
horn_boss_d = 7.8;
horn_arm_w = 3.5;
horn_long_r = 16;
horn_short_r = 7;
horn_cross_r = 7;
horn_screw_d = 2.2;
flag_wall_gap = 0.3;

color_housing = [0.95, 0.95, 0.95];
color_floor = [0.38, 0.40, 0.43];
color_flag = [0.18, 0.68, 0.27];

assert(wall >= 2.4, "Housing wall must remain structural.");
assert(tft_pocket_x >= tft_pcb_width + 0.8, "TFT pocket is undersized.");
assert(sensor_pocket_x >= sensor_pcb_x + 0.8, "Sensor pocket is undersized.");
assert(servo_pivot_z - servo_pivot_above_bottom >= 36,
       "Servo mount is not elevated.");

module rounded_rect_2d(x, y, r) {
    hull()
        for (px = [r, x - r])
            for (py = [r, y - r])
                translate([px, py]) circle(r = r);
}

// Analytic profile: full-width vertical walls topped by an upper semicircle.
module mailbox_profile_2d() {
    union() {
        square([mailbox_width, straight_wall_h + eps]);
        intersection() {
            translate([mailbox_width / 2, straight_wall_h])
                circle(r = roof_radius);
            translate([0, straight_wall_h])
                square([mailbox_width, roof_radius + eps]);
        }
    }
}

module mailbox_inner_profile_2d() {
    inner_r = roof_radius - wall;
    union() {
        translate([wall, -1])
            square([mailbox_width - 2 * wall, straight_wall_h + 1 + eps]);
        intersection() {
            translate([mailbox_width / 2, straight_wall_h])
                circle(r = inner_r);
            translate([wall, straight_wall_h])
                square([mailbox_width - 2 * wall, inner_r + eps]);
        }
    }
}

module cassette_limit_profile_2d() {
    limit_r = roof_radius - wall + 0.2;
    union() {
        translate([wall, -1])
            square([mailbox_width - 2 * wall, straight_wall_h + 1 + eps]);
        intersection() {
            translate([mailbox_width / 2, straight_wall_h])
                circle(r = limit_r);
            translate([wall, straight_wall_h])
                square([mailbox_width - 2 * wall, limit_r + eps]);
        }
    }
}

module profile_prism(length, inner = false) {
    translate([0, length, 0])
        rotate([90, 0, 0])
            linear_extrude(height = length, convexity = 10)
                if (inner) mailbox_inner_profile_2d();
                else mailbox_profile_2d();
}

module cassette_limit_prism() {
    translate([0, mailbox_length, 0])
        rotate([90, 0, 0])
            linear_extrude(height = mailbox_length, convexity = 10)
                cassette_limit_profile_2d();
}

module front_aperture_cuts() {
    window_x = tft_screen_width + 0.2;
    window_z = tft_screen_height + 0.2;
    translate([(mailbox_width - window_x) / 2, -eps,
               tft_center_z - window_z / 2])
        cube([window_x, wall + 2 * eps, window_z]);

    translate([mailbox_width / 2, -eps, button_center_z])
        rotate([-90, 0, 0])
            cylinder(h = wall + 2 * eps,
                     d = qbtn_shaft_d + 0.4);
}

module servo_and_service_cuts() {
    translate([mailbox_width - wall - eps, servo_pivot_y, servo_pivot_z])
        rotate([0, 90, 0])
            cylinder(h = wall + 2 * eps, d = 8.8);

    // Rear notch remains open to the bottom so the populated floor moves straight up.
    usb_center_x = floor_esp_x + esp_width / 2;
    translate([usb_center_x - (usb_width + 2) / 2,
               mailbox_length - wall - eps, -eps])
        cube([usb_width + 2, wall + 2 * eps, 12.0]);

    // Low side vents preserve the bottom seam and do not depend on buzzer alignment.
    for (yy = [78, 88, 98])
        translate([-eps, yy - 3.5, 14])
            cube([wall + 2 * eps, 7, 2.4]);
}

module sensor_roof_cut() {
    // The opening crosses the full roof skin over the sensor IC.
    translate([mailbox_width / 2 - 4.5, sensor_center_y - 4.5,
               straight_wall_h + roof_radius - wall - 0.5])
        cube([9, 9, wall + 1.2]);
}

module housing_snap_recesses() {
    for (yy = snap_y_positions) {
        translate([wall - 1.15, yy - snap_w / 2 - 0.4, 5.35])
            cube([1.25, snap_w + 0.8, 2.25]);
        translate([mailbox_width - wall - 0.1,
                   yy - snap_w / 2 - 0.4, 5.35])
            cube([1.25, snap_w + 0.8, 2.25]);
    }
}

module tft_cradle() {
    x0 = (mailbox_width - tft_pocket_x) / 2;
    x1 = x0 + tft_pocket_x;
    z0 = tft_center_z - tft_pocket_z / 2;
    z1 = z0 + tft_pocket_z;
    y0 = wall - 0.15;
    y1 = wall + tft_pocket_depth;
    rail = 1.8;
    keeper = 1.4;

    // Left guide and rear keeper.
    translate([x0 - rail, y0, z0 - 0.5])
        cube([rail, tft_pocket_depth + 1.4, tft_pocket_z + 1.0]);
    translate([x0 - rail, y1, z0 - 0.5])
        cube([rail + 3.8, keeper, tft_pocket_z + 1.0]);

    // Right guide is split to give the 10 mm FPC a side exit and bend volume.
    for (zr = [[z0 - 0.5, 7.3], [z0 + 20.0, z1 - (z0 + 20.0) + 0.5]]) {
        translate([x1, y0, zr[0]])
            cube([rail, tft_pocket_depth + 1.4, zr[1]]);
        translate([x1 - 2.0, y1, zr[0]])
            cube([rail + 2.0, keeper, zr[1]]);
    }

    // Top stop establishes screen alignment while leaving the bottom open.
    translate([x0 - rail, y0, z1])
        cube([tft_pocket_x + 2 * rail, tft_pocket_depth + 1.4, 1.8]);

    // Two printable vertical fingers retain the lower PCB edge.
    for (xx = [x0 + 3, x1 - 8]) {
        translate([xx, y1 + 0.05, 7.5])
            cube([5, 1.35, z0 - 7.5]);
        hull() {
            translate([xx, y1 + 0.05, z0 - 1.7])
                cube([5, 1.35, 0.2]);
            translate([xx, y1 - 0.85, z0 - 0.55])
                cube([5, 2.25, 0.55]);
        }
    }
}

module button_cradle() {
    pocket_x = qbtn_pcb_x + 0.8;
    pocket_z = qbtn_pcb_z + 0.8;
    x0 = (mailbox_width - pocket_x) / 2;
    x1 = x0 + pocket_x;
    z0 = 0.8;
    z1 = z0 + pocket_z;
    y0 = wall + tft_pocket_depth + 0.45;
    y1 = y0 + 3.8;
    rail = 1.6;

    // Split side rails leave independent left/right Qwiic cable paths.
    for (zr = [[z0, 5.0], [z0 + 13.0, z1 - (z0 + 13.0)]]) {
        translate([x0 - rail, y0, zr[0]])
            cube([rail, y1 - y0, zr[1]]);
        translate([x1, y0, zr[0]])
            cube([rail, y1 - y0, zr[1]]);
    }

    // Rear corner keepers provide positive depth retention without blocking cables.
    for (xx = [x0 - rail, x1 - 3.5])
        translate([xx, y1 - 1.35, z0])
            cube([5.1, 1.35, pocket_z]);

    translate([x0 - rail, y0, z1])
        cube([pocket_x + 2 * rail, y1 - y0, 1.6]);

    for (xx = [x0 + 1.5, x1 - 5.5]) {
        translate([xx, y1 - 1.3, 0])
            cube([4, 1.3, z0 + 0.25]);
        translate([xx, y1 - 1.3, z0])
            cube([4, 2.1, 0.8]);
    }
}

module servo_mount() {
    body_y0 = servo_pivot_y - 5.8 - rigid_clearance;
    body_y1 = body_y0 + servo_body_y + 2 * rigid_clearance;
    body_x0 = mailbox_width - wall - servo_body_x - 2 * rigid_clearance;
    body_z0 = servo_pivot_z - servo_pivot_above_bottom - rigid_clearance;
    body_z1 = body_z0 + servo_body_z + 2 * rigid_clearance;
    rib = 1.8;
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

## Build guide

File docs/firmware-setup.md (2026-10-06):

# Firmware Setup

This page documents the validated V1 firmware path. V2 hardware planning is in
[Mailbox V2 Build Plan](v2-build-plan.md); V2 firmware work still needs new
drivers/tests for the #2090 TFT microSD path, MAX98357A I2S audio, NeoPixel
Jewel, MPR121 touch input, DRV2605L haptics, and Hall sensor.

## Current Diagnostic

The first firmware milestone is a display-only smoke test. Keep the LiPo
battery, servo, and Qwiic devices disconnected.

### Required Software

- Arduino IDE 2.x
- Espressif `esp32` board package 3.3.11 or newer
- Adafruit ST7735 and ST7789 Library 1.11.0 or newer
- JPEGDEC 1.8.4 or newer

The Adafruit library installs Adafruit GFX and Adafruit BusIO automatically.

### Reproducible Release Build

The public release binary is intentionally compiled without
`EMBED_PROVISIONING_SECRETS`. It contains no Wi-Fi password, device key, or
deployment URL and reads previously provisioned values from NVS:

```powershell
arduino-cli compile `
  --fqbn "esp32:esp32:sparkfun_esp32c5_thing_plus:PartitionScheme=min_spiffs" `
  firmware\mailbox_firmware
```

Use the Minimal SPIFFS partition because the integrated firmware requires both
OTA slots and more application space than the default layout provides.

### Windows Application Control

On this Windows machine, Arduino CLI's bundled PyInstaller executables fail
before compilation or upload because Application Control blocks their
temporary Python DLLs. Do not retry `arduino-cli upload` or weaken the policy.
Use the repository helper, which:

- routes `gen_esp32part.py` through the installed policy-compatible Python;
- compiles with Arduino CLI and the verified Espressif core;
- uploads Arduino's generated `flash_args` through `python -m esptool`;
- retains esptool's per-region hash verification.

Compile:

```powershell
.\scripts\esp32c5-toolchain.ps1 `
  -Action Compile `
  -SketchDirectory .\firmware\mailbox_firmware `
  -BuildPath "$env:TEMP\mailbox-firmware-build" `
  -Fqbn "esp32:esp32:sparkfun_esp32c5_thing_plus:PartitionScheme=min_spiffs"
```

After explicit approval to change the connected device, upload:

```powershell
.\scripts\esp32c5-toolchain.ps1 `
  -Action Upload `
  -SketchDirectory .\firmware\mailbox_firmware `
  -BuildPath "$env:TEMP\mailbox-firmware-build" `
  -Port COM4
```

The helper was independently validated on 2026-09-18 by compiling the servo
smoke test at 324,384 bytes of program storage (24%) and 18,284 bytes of
dynamic memory (5%). The servo test was uploaded with installed Python and
esptool; every flash region passed hash verification.

### OTA Hash Rule

For OTA releases, `FIRMWARE_SHA256` must be the **ESP image validation hash**
from:

```powershell
python -m esptool image-info "<build-path>\mailbox_firmware.ino.bin"
```

Do not use `Get-FileHash` or the raw `.bin` SHA-256 for OTA metadata. The
firmware checks the OTA partition with `esp_partition_get_sha256`, which
matches the validation hash reported by `esptool image-info`.

### Board and Port

- **Board:** SparkFun ESP32-C5 Thing Plus
- **Arduino FQBN:** `esp32:esp32:sparkfun_esp32c5_thing_plus`
- **Upload port:** Select the COM port that identifies as Espressif USB

### V1 Display Smoke Test

Open:

`firmware/display_smoke_test/display_smoke_test.ino`

The test uses the exposed pins verified for the SparkFun board:

| Function | GPIO |
|---|---|
| SCK | IO10 |
| MOSI | IO8 |
| TCS | IO6 |
| DC | IO5 |
| RST | IO4 |
| LITE | IO3 |

Compile the sketch before uploading it. A successful test shows four colored
bands with `LOVE LETTER` at the top and `DISPLAY OK` at the bottom. The Serial
Monitor runs at 115200 baud.

Do not connect the servo or LiPo during this diagnostic.

### Servo Smoke Test

Keep the LiPo disconnected. Connect the SG90 through the mini breadboard:
orange signal through the purple jumper to IO1, red power through the yellow
jumper to VU/VUSB, and brown ground through the shared black GND row.

Compile with the policy-compatible helper:

```powershell
.\scripts\esp32c5-toolchain.ps1 `
  -Action Compile `
  -SketchDirectory .\firmware\servo_smoke_test `
  -BuildPath "$env:TEMP\servo-smoke-test-build"
```

Upload only while the yellow VUSB jumper is disconnected. After serial reports
stable center PWM, reconnect the yellow jumper and test one command at a time:
`1` for 1200 us, `2` for 1500 us, `3` for 1800 us, `4` for 1000 us, `5`
for 2000 us, and `x` to detach PWM. Commands `4` and `5` are the widest
physically validated nominal positions; they are not guaranteed mechanical
endpoints. The complete sequence passed physical validation on 2026-09-18
without continuous jitter, brownout, or reset.

For supervised calibration, send `p####`, where the pulse is from 800 through
2200 us in 50 us increments. Stop after every command to observe motion and
listen for sustained buzzing. Stepwise physical testing remained quiet across
the 800-2200 us envelope. The clearest conservative expanded range was
850-2150 us; do not infer that 800 and 2200 us are absolute mechanical stops.

## Servo-Free Message Integration

The next firmware milestone does not require the servo, LiPo, breadboard, or
protoboard. It runs from USB-C and uses the already validated display and
Qwiic chain.

1. Copy
   `firmware/mailbox_firmware/secrets.example.h` to
   `firmware/mailbox_firmware/secrets.h`.
2. Enter the local Wi-Fi name and password in `secrets.h`.
3. Provision a device key:

   ```powershell
   $env:STORAGE_ACCOUNT_NAME = "<storage-account-name>"
   $env:STORAGE_ACCOUNT_KEY = "<storage-account-key>"
   node scripts/provision-device-key.js recipient mailbox-recipient "<iana-time-zone>"
   ```

4. Copy the one-time plaintext key into `DEVICE_KEY` in `secrets.h`.
5. In Arduino IDE, select **Partition Scheme → Minimal SPIFFS (1.9MB APP
   with OTA/128KB SPIFFS)**. The default partition leaves insufficient
   firmware headroom.
6. Define `EMBED_PROVISIONING_SECRETS` only for the initial trusted USB
   provisioning build. Remove the define from normal and OTA release builds.
7. Compile and upload
   `firmware/mailbox_firmware/mailbox_firmware.ino`.

`secrets.h` is excluded from Git. The firmware uses HTTPS certificate
validation through the ESP-IDF root certificate bundle; it does not use an
insecure TLS mode.

### Queue-Mode Acceptance Test

1. Send a text message to the mailbox from the web app.
2. Confirm the landscape display enters the animated floating-hearts
   screensaver after two minutes without a button interaction. Confirm the
   central panel remains stable without full-screen blinking while the hearts
   move along its sides.
3. Send a photo message while the screensaver is active. Confirm the playful
   Qwiic buzzer notification sounds only after queued image prefetch is
   attempted, and the screensaver remains visible.
4. Press the button once and confirm the cached current message appears
   immediately without being marked read.
5. Press the button again and confirm the message is marked read, removed from
   ESP memory, and the next queued unread message appears immediately.
6. If there are no queued unread messages, confirm the display returns to the
   idle state, the red Qwiic Button LED turns off, and the servo flag lowers.
7. Cover and uncover the light sensor and confirm the backlight changes.

The physical button intentionally has no back-scroll, double-click, or
long-press behavior. Every non-screensaver press means read the current message
and advance the unread queue.

The Qwiic buzzer is a tone generator, not an audio playback device. Firmware
v1.2.6 uses an original playful multi-beep arrival pattern.

V2 will use different audio hardware: media files downloaded by the ESP32,
stored on the #2090 TFT microSD card, and played over I2S through a MAX98357A
amplifier and enclosed speaker. Spoken phrases, songs, or character-voice
laughs must use licensed/original audio assets and the V2 audio path, not the
Qwiic buzzer.

## Photo Rendering

The API stores baseline JPEG derivatives that fit inside 216×160 while
preserving the source aspect ratio and portrait/landscape orientation. The
firmware centers the image in the display region without cropping or
stretching.

The ESP32 polls only the unread queue and retains metadata for up to 20 queued
unread messages. It caches image bytes for at most four messages using LRU
eviction, reserves internal heap and PSRAM headroom before each allocation, and
evicts a message's cached image immediately after that message is marked read.
Each downloaded JPEG is limited to 512KB; an unavailable or invalid image
produces a visible fallback instead of exhausting memory or crashing.

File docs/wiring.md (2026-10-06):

# V1 Wiring Guide

This page documents the validated V1 wiring. V2 changes the display, media
storage, audio, heart input/output, haptics, flag sensing, battery, and internal
tray layout; see [Mailbox V2 Build Plan](v2-build-plan.md) before wiring the
next revision.

## Overview

The V1 mailbox uses two communication interfaces:
- **SPI** — for the TFT display (8 wires including power and backlight)
- **Qwiic (I2C)** — for the light sensor, buzzer, and button (daisy-chained, no soldering)

Plus one **PWM signal wire** for the servo.

---

## SparkFun Thing Plus ESP32-C5 Pinout Reference

The verified SparkFun ESP32-C5 Thing Plus pins for this project are:

| Function | ESP32-C5 Pin | Notes |
|---|---|---|
| SPI MOSI | IO8/PICO | Display data |
| SPI SCLK | IO10/SCK | Display clock |
| TFT CS | IO6 | Display chip select |
| TFT DC | IO5 | Display data/command |
| TFT RST | IO4 | Display reset |
| TFT LITE | IO3 | Display backlight (PWM for dimming) |
| Servo Signal | IO1 | PWM-capable exposed pin; physically validated with the SG90 |
| Qwiic SDA | IO23 | I2C data through the onboard Qwiic connector |
| Qwiic SCL | IO24 | I2C clock through the onboard Qwiic connector |
| USB 5V | VUSB | Servo power |
| 3.3V | 3V3 | Display power |
| GND | GND | Common ground |

> These assignments match the SparkFun Arduino board definition and the
> physically completed wiring. IO13, IO14, IO15, and IO18 are not exposed on
> the board headers.

---

## TFT Display Wiring (SPI)

Connect the V1 2.0" ST7789 display to the ESP32-C5:

| EYESPI Pin | ESP32-C5 Pin | Installed Wire Color |
|---|---|---|
| GND | GND | Black |
| VIN | 3V3 | Brown |
| SCK | IO10/SCK | White |
| MOSI | IO8/PICO | Red |
| TCS | IO6 | Yellow |
| DC | IO5 | Green |
| RST | IO4 | Blue |
| LITE | IO3 | Orange |

**Important:**
- VCC must be **3.3V**, not 5V
- MISO is intentionally unused
- LITE controls the backlight and is connected to IO3 for software dimming
- The initial USB-C power test illuminated the backlight but did not validate
  SPI data or image rendering

---

## Servo Wiring

The ESP32-C5 is installed across the center channel of a mini breadboard. Each
jumper connects through the breadboard row shared with the corresponding ESP32
header pin; no connectors are stacked directly on a header pin.

Connect the SG90 micro servo:

| Servo Lead | Jumper Color | ESP32-C5 Connection |
|---|---|---|
| Orange (signal) | Purple | IO1 shared breadboard row |
| Red (power) | Yellow | VU/VUSB shared breadboard row |
| Brown (ground) | Black | Common GND breadboard row |

The display ground, ESP32 ground, and servo ground share the same breadboard
row. This wiring was physically validated on 2026-09-18.

**Important:**
- Power the servo from the **5V USB rail** (VUSB pin), not 3.3V. Servos need 4.8-6V.
- Use IO1 for the servo signal. IO18 is not exposed on this board.
- Detach PWM after each completed movement to reduce idle jitter and current.
- Keep the servo signal wire physically separated from the SPI wires to avoid noise.

### Servo Smoke Test

`firmware/servo_smoke_test/servo_smoke_test.ino` starts at center with bounded
50 Hz pulses and accepts these serial commands at 115200 baud:

| Command | Result |
|---|---|
| `1` | Left test position, 1200 us |
| `2` | Center position, 1500 us |
| `3` | Right test position, 1800 us |
| `4` | Wide left test position, 1000 us |
| `5` | Wide right test position, 2000 us |
| `p####` | Manual calibration pulse, 800-2200 us in 50 us steps |
| `x` | Detach PWM and hold IO1 low |

Physical validation passed on 2026-09-18: left, center, and right produced
controlled movement followed by silence. A white arm then made the wider
1000-2000 us traversal clearly visible in both directions without sustained
buzzing or reaching an observed hard stop. Detach disabled the signal. No
continuous jitter, brownout, or board reset occurred.

Treat 1000-2000 us as the physically validated nominal operating range, not as
proof of the servo's absolute mechanical endpoints.

Further stepwise calibration on 2026-09-18 tested 950/2050, 900/2100,
850/2150, and 800/2200 us. The servo remained quiet without jitter, brownout,
or reset. Travel was clearly greater at 850 and 2150 us. Additional leftward
travel at 800 us was difficult to distinguish, while 2200 us still produced
visible rightward travel. Use 850-2150 us as the conservative expanded
operating range; 800-2200 us is the tested envelope, not a confirmed pair of
mechanical endpoints.

---

## Qwiic Daisy-Chain (I2C — No Soldering)

All three Qwiic peripherals connect via snap-in cables:

```
ESP32-C5 Qwiic Port
    │
    │  [Qwiic Cable 200mm]
    │
    ▼
Qwiic Button (0x6F)
    │
    │  [Qwiic Cable 200mm]
    │
    ▼
VEML6030 Light Sensor (0x48)
    │
    │  [Qwiic Cable 200mm]
    │
    ▼
Qwiic Buzzer (0x34)
```

**That's it.** Just click the cables in. Each board has two Qwiic connectors (IN and OUT). The order doesn't matter electrically, but the above order keeps cable runs logical inside the enclosure.

### I2C Address Table

| Device | I2C Address | Qwiic? |
|---|---|---|
| VEML6030 Light Sensor | 0x48 | Yes |
| Qwiic Buzzer (ATtiny84) | 0x34 | Yes |
| Qwiic Button | 0x6F | Yes |
| MAX17048 Fuel Gauge (onboard) | 0x36 | Onboard — no wiring |

No V1 address conflicts. All four devices coexist on the same I2C bus.

V2 will add at least the MPR121 capacitive touch sensor and DRV2605L haptic
controller to the I2C plan. Run an I2C scanner before final V2 wiring and
resolve any address conflict before mounting the boards.

---

## LiPo Battery

Plug the JST-PH connector into the battery port on the Thing Plus. That's it.

- The onboard MCP73831 charges the battery automatically when USB is connected
- The onboard MAX17048 fuel gauge reports battery voltage and percentage via I2C
- Charge rate: ~214mA at 3.3V

---

## Complete Wiring Summary

```
                    ┌─────────────────────────┐
                    │   ESP32-C5 Thing Plus    │
                    │                         │
 ┌── TFT Display ──┤ IO10    ← SCK            │
 │   (SPI, 8 wires)│ IO8     ← MOSI           │
 │                  │ IO6     ← TCS            │
 │                  │ IO5     ← DC             │
 │                  │ IO4     ← RST            │
 │                  │ IO3     ← LITE           │
 │                  │ 3V3     ← VIN            │
 │                  │ GND     ← GND           │
 │                  │                         │
 ├── Servo ────────┤ IO1     ← Signal        │
 │   (3 wires)     │ VUSB    ← VCC (5V)      │
 │                  │ GND     ← GND           │
 │                  │                         │
 ├── Qwiic Chain ──┤ Qwiic Port (snap-in)    │
 │   (cables only) │ → Light Sensor           │
 │                  │   → Buzzer              │
 │                  │     → Button            │
 │                  │                         │
 └── LiPo Battery ┤ JST Battery Port        │
                    │                         │
                    │ USB-C ← Power + Flash   │
                    └─────────────────────────┘
```

---

## Tools Needed

- Soldering iron + solder (for display header pins, if not pre-soldered)
- Wire strippers
- Small Phillips screwdriver (for servo horn)
- USB-C cable
- Computer with Arduino IDE

---

## Testing After Wiring

1. **Before powering on:** Double-check all connections, especially VCC voltages (3.3V for display, 5V for servo)
2. **Power on via USB-C**
3. Flash `firmware/display_smoke_test/display_smoke_test.ino`
4. **Serial Monitor (115200 baud):** Confirm `Display pattern rendered.`
5. **Expected result:** Four colored bands, `LOVE LETTER`, and `DISPLAY OK`

The V1 display, Qwiic chain, and servo smoke tests have passed. WiFi
provisioning and integrated mailbox validation remain separate tests. V2 wiring
must be validated separately after the #2090 TFT/microSD, MAX98357A, NeoPixel,
MPR121, DRV2605L, Hall sensor, and battery layout are finalized.

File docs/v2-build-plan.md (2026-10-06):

# Mailbox V2 Build Plan

> Status: V2 hardware architecture and bill of materials captured 2026-10-06.
> This public project document intentionally excludes order numbers, delivery
> addresses, phone numbers, and payment details.

## V2 Goal

V2 moves the physical mailbox from the V1 read-and-chime prototype toward a
feature-first build with richer interaction:

- larger portrait display
- OTA-updatable picture and audio media cache
- real speaker/audio playback
- translucent glowing heart
- capacitive heart-back interaction
- haptic heartbeat feedback
- flag position sensing
- larger battery
- redesigned internal tray that fits the real soldered-header ESP32 board

The guiding rule for this revision is to solve the feature architecture before
committing to enclosure geometry or one-off hardware shortcuts.

## Architecture Decisions

| Area | V2 decision | Rationale |
|---|---|---|
| Controller | Reuse SparkFun Thing Plus ESP32-C5 | V1 already validated Wi-Fi, HTTPS polling, OTA, Qwiic, display, and battery behavior on this board |
| Display | Move to Adafruit 2.8" TFT LCD with capacitive touch and EYESPI/microSD, Product ID 2090 | Larger portrait screen, EYESPI cabling path, onboard microSD socket |
| Media storage | Store downloaded pictures and audio on the TFT #2090 microSD card | Keeps heavy media out of ESP32 flash and lets firmware manage OTA-downloaded assets |
| Audio | ESP32-managed playback: microSD media -> I2S -> MAX98357A amp -> enclosed speaker | Supports OTA media updates; avoids a separate audio board whose SD card is not ESP32-managed |
| Heart input | Copper foil electrode + MPR121 capacitive touch sensor | Enables heart-back / reply interaction without relying only on a push button |
| Heart output | Translucent printed heart + NeoPixel Jewel backlight | Makes the heart part of the enclosure instead of an external indicator |
| Haptics | DRV2605L haptic controller + vibrating mini motor disc | Adds heartbeat/tactile notification patterns |
| Flag sensing | Digital Hall-effect sensor + small magnet / reed-switch fallback | Lets firmware detect or confirm when the physical flag is lowered |
| Battery | Redesign around 2200mAh cylindrical LiIon battery | Larger display, audio, LEDs, and haptics increase power demand |
| Mechanical baseline | Redesign floor/tray from scratch | The existing tray does not account for ESP32 bottom-soldered headers or the cylindrical battery |

## Bill of Materials

### Reused / Already In Stock

| Part | Qty | Source | Build purpose |
|---|---:|---|---|
| SparkFun Thing Plus ESP32-C5 | 1 | In stock | Main controller, Wi-Fi, OTA, Qwiic, LiPo charging |
| 18-pin EYESPI FPC cable | 1 | In stock | Display-to-host cabling path |
| EYESPI breakout / host-side wiring path | 1 | In stock | Prototyping and signal breakout |
| SparkFun Qwiic Button with LED | 1 | In stock | Physical fallback / alternate interaction control |
| SparkFun VEML6030 ambient light sensor | 1 | In stock | Auto-dim / ambient-light input |
| SG90 micro servo | 1 | In stock | Mailbox flag actuation |
| Qwiic cables | As needed | In stock | I2C daisy-chain wiring |

### Ordered for V2

| Product ID / Item | Qty | Build purpose |
|---|---:|---|
| Adafruit #2090, 2.8" TFT LCD with capacitive touch, EYESPI connector, and microSD socket | 1 | Larger display and ESP32-accessible media storage |
| Adafruit #3006, MAX98357A I2S 3W Class-D mono amplifier | 1 | ESP32-managed audio playback |
| Adafruit #3351, mono enclosed speaker, 3W 4 ohm | 1 | Audio output |
| ScoutMakes / Adafruit #6051, DRV5032 digital magnetic Hall-effect sensor | 1 | Flag position sensing |
| Adafruit #375, magnetic contact switch | 1 | Magnet source / fallback contact sensor |
| Adafruit #1781, 3.7V 2200mAh cylindrical LiIon battery | 1 | Larger V2 power reserve |
| Adafruit #2226, NeoPixel Jewel | 1 | Translucent heart glow / pulse |
| Adafruit #4830, MPR121 capacitive touch sensor | 1 | Touch-heart / heart-back input |
| Adafruit #1127, copper foil tape with conductive adhesive | 1 | Touch electrode behind or around the heart |
| Adafruit #2305, DRV2605L haptic motor controller | 1 | Heartbeat vibration effects |
| Adafruit #1201, vibrating mini motor disc | 1 | Haptic output |
| Adafruit #3314, half-size breadboard + jumper bundle | 1 | ESP32 fanout/prototyping and shared power/ground rows |
| Lexar E-Series 32GB microSDHC UHS-I card, 3-pack | 1 | Media cache for downloaded pictures and audio files |

### Still Pending After CAD Review

| Item | Why it remains pending |
|---|---|
| Speaker gasket, grille, and acoustic chamber details | Depends on speaker placement and enclosure vent geometry |
| M2/M2.5 screws, heat-set inserts, or self-tapping screws | Depends on final display, speaker, sensor, and tray mounts |
| Optional separate microSD breakout | Only needed if the #2090 TFT microSD slot is mechanically inaccessible or electrically inconvenient |

## Media and OTA Model

The ESP32 should own the media lifecycle:

1. Poll backend for message metadata and media URLs.
2. Download images and audio over HTTPS.
3. Store large media assets on the microSD card.
4. Keep firmware, credentials, and lightweight configuration in ESP32 flash.
5. Use a cache cleanup policy so old media does not fill the card.

This replaces the earlier SparkFun WAV Trigger / Qwiic Speaker Amp path. That
path remains on hold because its audio files live on the audio board's own SD
card rather than storage managed directly by the ESP32 firmware.

## Mechanical Design Implications

The existing V1/V2 tray assumptions are obsolete:

- The ESP32-C5 has soldered bottom headers/pins and cannot sit flush in the
  previous tray model.
- The Adafruit #1781 battery is a cylindrical 69mm x 18mm cell, not a flat LiPo
  pouch.
- The display, speaker, haptic motor, Hall sensor, NeoPixel, copper electrode,
  MPR121 board, and microSD access all need serviceable placement.

The next enclosure revision should model:

- raised ESP32 clearance or breadboard-style fanout
- lengthwise or crosswise #1781 battery placement
- #2090 display mount with microSD access path
- translucent printed heart insert
- NeoPixel cavity behind the heart
- copper electrode behind or around the heart
- haptic motor bonded to a surface that can transmit vibration
- speaker chamber and vent path
- Hall sensor and magnet alignment for flag state detection

## Wiring / Address Notes To Validate

| Item | Validation needed |
|---|---|
| #2090 TFT + microSD sharing | Confirm SPI chip-select assignments and whether TFT + SD can share the same bus cleanly |
| MAX98357A | Select I2S BCLK, LRCLK, and DIN pins that do not conflict with display SPI or servo |
| MPR121 and DRV2605L | Check default I2C addresses before final wiring; if both occupy the same address, change the MPR121 address |
| NeoPixel Jewel | Pick a free GPIO and add level/power considerations if brightness is high |
| Hall sensor | Decide pull-up/down behavior and magnet placement after flag geometry is modeled |
| Power budget | Recalculate current draw for TFT backlight, NeoPixels, audio amp, haptics, servo, and ESP32 Wi-Fi bursts |

## Build Sequence

1. Confirm the new component footprints and connector orientations.
2. Breadboard the new I2C devices and scan addresses.
3. Validate TFT #2090 display and microSD access from the ESP32.
4. Validate SD-backed image read/write and simple cache cleanup.
5. Validate MAX98357A I2S audio playback from a file on microSD.
6. Validate NeoPixel Jewel brightness through translucent printed samples.
7. Validate MPR121 touch-heart detection through the printed heart/copper stack.
8. Validate DRV2605L haptic effects and motor placement.
9. Validate Hall sensor/magnet flag-state detection.
10. Redesign the enclosure floor/tray around validated placements.
11. Print a fit coupon before committing to a full enclosure print.

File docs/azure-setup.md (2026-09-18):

# Azure Backend Setup

## Prerequisites

- Azure CLI installed (`az --version`)
- Visual Studio Enterprise subscription (or any Azure subscription)
- Login via: `az login --use-device-code` (use alternate account if corp CA blocks CLI)

## What Was Deployed

| Resource | Type | Name | Location |
|---|---|---|---|
| Resource Group | `Microsoft.Resources/resourceGroups` | `love-letter-mailbox` | West US 2 |
| Storage Account | `Microsoft.Storage/storageAccounts` | `lovelettermlbx` | West US 2 |
| Table Storage | Table | `messages` | (in lovelettermlbx) |
| Blob Container | Container | `photos` | (in lovelettermlbx) |
| Blob Container | Container | `firmware` | (in lovelettermlbx) |

### Seed Paired Users

The seed script has no default identities or passwords. Configure both paired
accounts explicitly:

```powershell
$env:STORAGE_ACCOUNT_NAME = "<storage-account-name>"
$env:STORAGE_ACCOUNT_KEY = "<storage-account-key>"
$env:MAILBOX_USER_A = "sender"
$env:MAILBOX_USER_A_DISPLAY_NAME = "Sender"
$env:MAILBOX_USER_A_PASSWORD = "<strong-password>"
$env:MAILBOX_USER_B = "recipient"
$env:MAILBOX_USER_B_DISPLAY_NAME = "Recipient"
$env:MAILBOX_USER_B_PASSWORD = "<strong-password>"
node scripts\seed-users.js
```

Set `ADMIN_USERNAME` in the Static Web App configuration if moderation
violations should also create an alert message in an administrator mailbox.

### Provision a Physical Mailbox

Device keys are not stored as application settings. Provision each physical
mailbox with a unique key whose SHA-256 hash is stored in the `devicekeys`
table:

```powershell
$env:STORAGE_ACCOUNT_NAME = "<storage-account-name>"
$env:STORAGE_ACCOUNT_KEY = "<storage-account-key>"
node scripts/provision-device-key.js recipient mailbox-recipient "<iana-time-zone>"
```

Copy the one-time plaintext key directly into the device's ignored
`firmware/mailbox_firmware/secrets.h` file. Never commit or reuse it.

### Normalize Existing Message Photos

New uploads are normalized by the API to an aspect-ratio-preserving baseline
JPEG within 216×160. Existing blobs can be assessed with the migration utility:

```powershell
$env:STORAGE_ACCOUNT_NAME = "<storage-account-name>"
$env:STORAGE_ACCOUNT_KEY = "<storage-account-key>"
node web\api\scripts\migrate-message-photos.js
```

Dry run is the default and makes no Azure changes. Review its ignored local
manifest under `local/migrations/` before applying:

```powershell
node web\api\scripts\migrate-message-photos.js --apply
```

Apply mode uploads an immutable `-device-v1.jpg` derivative and only then
updates the message entity. It preserves the original blob and records
`photoOriginalUrl` for rollback; it never overwrites or deletes the source.

### Manual Production Deployment

Run SWA CLI from the repository root, not from inside `web`. Running inside
the deployment source causes the client's temporary artifact folder to overlap
the source tree and the upload fails. On Windows, first add the Azure Linux x64
Sharp runtime to the local dependency tree:

```powershell
npm --prefix web\api run prepare:swa

swa deploy web `
  --api-location web\api `
  --swa-config-location web `
  --api-language node `
  --api-version 22 `
  --deployment-token $env:SWA_CLI_DEPLOYMENT_TOKEN `
  --env production
```
| Static Web App | `Microsoft.Web/staticSites` | `love-letter-app` | West US 2 |

**Static Web App URL:** https://zealous-dune-001e8941e.7.azurestaticapps.net

## Deployment Commands (Reproducible)

### 1. Login

```powershell
# Use device code flow if corporate Conditional Access blocks interactive login
az login --use-device-code
# Sign in with alternate account (e.g., personal Microsoft account linked to VS Enterprise)
```

### 2. Set Subscription

```powershell
az account set --subscription "<subscription-id>"
```

### 3. Create Resource Group

```powershell
az group create --name love-letter-mailbox --location westus2
```

### 4. Register Required Resource Providers

```powershell
az provider register --namespace Microsoft.Storage
az provider register --namespace Microsoft.Web
```

> **Note:** New VS Enterprise subscriptions don't have resource providers pre-registered. This is a one-time step.

### 5. Create Storage Account

```powershell
az storage account create \
  --name lovelettermlbx \
  --resource-group love-letter-mailbox \
  --location westus2 \
  --sku Standard_LRS \
  --kind StorageV2
```

> **Note:** Storage account names are globally unique. `loveletterstore` was taken; `lovelettermlbx` worked.

### 6. Create Table and Blob Containers

```powershell
$key = (az storage account keys list --account-name lovelettermlbx --resource-group love-letter-mailbox --query "[0].value" -o tsv)

az storage table create --name messages --account-name lovelettermlbx --account-key $key
az storage container create --name photos --account-name lovelettermlbx --account-key $key
az storage container create --name firmware --account-name lovelettermlbx --account-key $key
```

### 7. Create Static Web App

```powershell
az staticwebapp create \
  --name love-letter-app \
  --resource-group love-letter-mailbox \
  --location westus2 \
  --sku Free
```

## Troubleshooting

### "SubscriptionNotFound" when creating resources
- The subscription shows in `az account show` but ARM rejects it
- **Root cause:** Likely a globally-taken storage account name, NOT a subscription issue
- **Fix:** Try a different storage account name

### Error 53003 (Conditional Access)
- Corp accounts may be blocked from Azure CLI by Conditional Access policy
- **Fix:** Use an alternate personal account linked to your Azure subscription
- Login flow: `az login --use-device-code` → sign in with personal account → complete MFA

### "MissingSubscriptionRegistration"
- New VS Enterprise subscriptions don't have all resource providers registered
- **Fix:** `az provider register --namespace Microsoft.Web` (one-time per provider)

## Monthly Cost

| Resource | Cost |
|---|---|
| Static Web App (Free tier) | $0.00 |
| Table Storage (messages) | ~$0.01 |
| Blob Storage (photos + firmware) | ~$0.01 |
| **Total** | **~$0.02/mo** |

Covered by VS Enterprise monthly credit ($150/mo).

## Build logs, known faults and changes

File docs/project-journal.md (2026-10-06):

# Project Journal & Scope Tracker

## Original Scope

**Goal:** Replicate the [Love Letter Tech](https://lovelettertech.com) mailbox — a WiFi-connected device that displays text messages and photos, with a flag that rises on new messages.

### Love Letter Tech Feature Set (Baseline)

| # | Feature | In Original Product | In Our Build | Status |
|---|---|---|---|---|
| 1 | Text messaging (phone → device) | ✅ | ✅ | Planned |
| 2 | Photo messaging | ✅ | ✅ | Planned |
| 3 | Servo flag (raise on new msg) | ✅ | ✅ | Planned |
| 4 | Color TFT display | ✅ | ✅ | Planned |
| 5 | WiFi connectivity | ✅ (2.4GHz) | ✅ (dual-band) | Upgraded |
| 6 | Companion mobile app | ✅ (iOS + Android) | ❌ (web page) | Simplified |
| 7 | QR code pairing | ✅ | ❌ | Descoped |
| 8 | WiFi provisioning | ✅ (via app) | ✅ (captive portal) | Different approach |
| 9 | Multi-sender support | ✅ | ✅ | Planned |
| 10 | Encrypted transit | ✅ | ✅ (HTTPS) | Planned |

---

## Scope Creep Tracker

Features we added **beyond** the original Love Letter Tech product:

| # | Added Feature | Justification | Scope Impact | Cost Impact |
|---|---|---|---|---|
| 1 | **Dual-band WiFi 6 (ESP32-C5)** | Eliminates #1 failure mode (2.4GHz band-steering). Research-driven decision. | Hardware upgrade | +$19/unit |
| 2 | **LiPo battery backup** | Eliminates brownout resets during WiFi TX bursts | Hardware add | +$13.61 |
| 3 | **Ambient light sensor (auto-dim)** | Night-friendly — display won't blind you at 2am | Hardware add | +$6 |
| 4 | **Notification buzzer** | Audible alert on message arrival | Hardware add | +$7 |
| 5 | **Physical button** | Mark as read, scroll messages | Hardware add | +$5 |
| 6 | **OTA firmware updates** | Remote updates for device at fiancée's house | Firmware feature | $0 |
| 7 | **Azure cloud backend** | Enterprise-grade hosting vs Firebase | Architecture change | ~$0.02/mo |
| 8 | **Open-source documentation** | Public GitHub repo with full docs | Documentation | Time only |
| 9 | **Battery fuel gauge monitoring** | Comes free with ESP32-C5 Thing Plus | Firmware feature | $0 |
| 10 | **Read heart receipts in sent view** | Gives the sender confirmation when each message has been read | Backend + web UX | $0 |

### Scope Creep Score

| Metric | Value |
|---|---|
| **Original features replicated** | 8 of 10 (80%) |
| **Features descoped** | 2 (native app, QR pairing) |
| **Features added beyond original** | 10 |
| **Scope creep ratio** | 10 added ÷ 10 baseline = **1.0x** |
| **Cost creep** | $129 (commercial) → $92 (DIY) = **29% cheaper** despite more features |
| **Complexity creep** | Medium — most additions are Qwiic snap-in (no extra code complexity) |

### Scope Creep Assessment

**Verdict: Justified scope creep.** Every addition was driven by the failure analysis:
- Items 1-2 eliminate hardware failure modes
- Items 3-5 are Qwiic snap-in (minimal complexity cost)
- Item 6 is essential for remote deployment
- Item 7 leverages existing Azure credits
- Item 8 was a deliberate choice for public sharing

**Features we wisely DIDN'T add (yet):**
- ❌ Voice messages (I2S DAC + speaker — v2)
- ❌ Emoji rendering (custom fonts — v2)
- ❌ Weather display (API integration — v2)
- ✅ Read heart receipts in the sent-message view
- ❌ Multiple device pairing (group messaging — v2)
- ❌ E-ink display option (different hardware — v2)

---

## Session Log

### 2026-10-06 (Tue) — V2 Hardware Architecture and BOM

- Captured the V2 hardware direction in `docs/v2-build-plan.md`.
- Reframed audio hardware around the feature requirement: OTA-updatable media
  files owned by the ESP32, not a separate audio board with its own unmanaged SD
  card.
- Selected the preferred V2 media/audio path: ESP32 HTTPS download -> TFT #2090
  microSD media cache -> I2S -> MAX98357A amplifier -> enclosed speaker.
- Recorded the final V2 purchase set: Adafruit #2090 display, #3006 MAX98357A,
  #3351 speaker, #6051 Hall sensor, #375 magnetic contact switch/magnet path,
  #1781 cylindrical battery, #2226 NeoPixel Jewel, #4830 MPR121, #1127 copper
  tape, #2305 DRV2605L, #1201 vibration motor, #3314 breadboard/jumpers, and
  Lexar 32GB microSD cards.
- Dropped the EL wire/inverter path for now; V2 uses a translucent printed heart
  backed by a NeoPixel Jewel plus copper touch electrode and haptic feedback.
- Marked the prior internal tray model obsolete because it does not account for
  ESP32 bottom-soldered headers or the selected cylindrical battery.
- Listed the next physical-design requirements: serviceable #2090 microSD
  access, speaker chamber/vent path, haptic motor placement, Hall sensor/magnet
  alignment, translucent heart geometry, and a fit coupon before a full
  enclosure print.

### 2026-08-24 (Mon) — Afternoon

**Duration:** ~2.5 hours

#### Research Phase (14:51 - 15:40)
- Analyzed lovelettertech.com product and UMass Lowell article about creator Owen O'Brien
- Identified full feature set to replicate
- Researched common ESP32 IoT failure modes (WiFi, power, cloud, photos)
- Compared backend options: Firebase vs MQTT+Telegram vs ntfy.sh vs Azure
- Evaluated display sizes (1.3" through 2.8"), selected 2.0" ST7789
- Developed 3 architecture proposals, scored iteratively to 9.7/10

#### Hardware Selection (15:40 - 16:10)
- Discovered ESP32-C5 as solution to 2.4GHz WiFi problem
- Selected SparkFun Thing Plus ESP32-C5 ($24.95)
- Identified Qwiic ecosystem for peripherals (light sensor, buzzer, button)
- Selected LiPo 850mAh for battery backup
- **Ordered from SparkFun:** 2× ESP32-C5, 2× LiPo, light sensor, buzzer, button, 3× Qwiic cables
- **Ordered from Amazon:** 2-pack 2.0" ST7789 TFT displays

#### Architecture Decision (15:48 - 15:52)
- Decided on Azure Static Web App + Table Storage (Option 2)
- Leveraging VS Enterprise Azure credits ($150/mo)
- Scored final architecture: Easy 9, Cost 10, Failure Resistant 10 = **9.7 avg**

#### Documentation (16:32 - 16:57)
- Created full project folder structure
- Wrote README.md with architecture diagram, BOM, cost comparison
- Wrote docs/architecture.md with design decisions and failure analysis
- Wrote docs/bom.md with complete parts list and alternatives
- Wrote docs/wiring.md with pin maps and Qwiic chain diagram
- Wrote docs/ota-updates.md with remote update guide
- Wrote docs/troubleshooting.md with common issues and fixes
- Created MIT LICENSE

#### Azure Deployment (17:10 - 17:33)
- Activated VS Enterprise subscription via alternate personal account
- Worked around corporate Conditional Access (Error 53003) using device code flow
- Deployed Azure resources:
  - Resource group: `love-letter-mailbox`
  - Storage account: `lovelettermlbx`
  - Table: `messages`
  - Blob containers: `photos`, `firmware`
  - Static Web App: `love-letter-app`
  - **Live URL:** https://zealous-dune-001e8941e.7.azurestaticapps.net

#### Key Decisions Made
1. ESP32-C5 over classic ESP32 (dual-band WiFi, PSRAM)
2. Azure over Firebase (existing credits, Microsoft infrastructure)
3. Web page over native app (no app store, works on any device)
4. HTTP polling over MQTT (simpler, no connection state)
5. Qwiic peripherals over raw components (no soldering, snap-in)
6. Public open-source over private project

#### Blockers
- GitHub account not yet created (deferred)
- Azure CLI blocked by corp CA — workaround: alternate personal account with device code flow

#### Next Steps
- [x] Create GitHub account and push repo — https://github.com/dbsargent-test/love-letter-mailbox
- [x] Build messaging web page (HTML/JS) — SPA with Creative Studio, i18n (EN/ES), content moderation
- [x] Write Azure Functions API (send/receive messages) — auth, messages, contacts, device endpoints
- [x] Set up email service (Azure Communication Services) — forgot-password flow verified
- [x] Security audit & hardening — 21 findings fixed, 22/24 live tests passed
- [ ] Register GIPHY API key for GIF search (optional)
- [ ] Extract inline JS to external file (remove CSP `unsafe-inline`)
- [x] Write complete ESP32-C5 firmware for V1 message/photo/read-heart flow
- [x] Compile, flash, and visually verify the ST7789 display diagnostic
- [x] Design and physically validate the V1 3D printable enclosure
- [x] Build servo flag notification for V1
- [x] Test V1 end-to-end with physical hardware
- [ ] Build V2 translucent heart glow/touch/haptic interaction

### 2026-09-16 (Wed) — Display Firmware Validation

- Installed Arduino IDE 2.3.10 and Espressif Arduino core 3.3.11.
- Selected the official `esp32:esp32:sparkfun_esp32c5_thing_plus` board target.
- Installed Adafruit ST7735/ST7789 1.11.0, GFX 1.12.6, and BusIO 1.17.4.
- Added `firmware/display_smoke_test/display_smoke_test.ino`.
- Compiled successfully: 356,258 bytes of flash and 19,664 bytes of RAM.
- Flashed the diagnostic to COM4; all four flash regions passed hash
  verification.
- Serial confirmed SCK 10, MOSI 8, CS 6, DC 5, RST 4, and LITE 3, then printed
  `Display pattern rendered.`
- Visually verified four colored bands plus `LOVE LETTER` and `DISPLAY OK`.
- Kept the LiPo, servo, and Qwiic devices disconnected throughout the test.
- Connected the first keyed Qwiic cable from the ESP32-C5 to the red Qwiic
  Button.
- Added, compiled, and flashed
  `firmware/qwiic_button_smoke_test/qwiic_button_smoke_test.ino`.
- Verified Button address `0x6F`, device ID `0x5D`, SDA `IO23`, and SCL `IO24`.
- Physically verified press/release detection, onboard Button LED control, and
  green/blue TFT status changes.
- Connected the Button's unused Qwiic port to the VEML6030 light sensor.
- Added, compiled, and flashed
  `firmware/qwiic_chain_smoke_test/qwiic_chain_smoke_test.ino`.
- Verified the VEML6030 at `0x48`; serial values changed from 9 to 118 lux as
  the sensor was covered and uncovered, and the TFT showed 124 lux.
- Connected the VEML6030 to the Qwiic Buzzer, completing the full daisy-chain.
- Installed SparkFun Qwiic Buzzer Library 1.1.0 and SparkFun Toolkit 1.2.0.
- Extended the chain diagnostic to detect the Buzzer at `0x34`, play a 150 ms
  medium-volume startup tone, and beep on button presses.
- Full-chain firmware compiled at 28% flash and 6% RAM and flashed with all
  regions hash-verified.
- Serial confirmed all three addresses, and the startup confirmation tone was
  heard.
- Deferred the SG90 servo until a proper common-ground distribution point is
  available; the display already occupies the ESP32-C5 header GND pin.
- Added the first integrated, servo-free mailbox firmware for authenticated
  HTTPS polling, oldest-unread text display, buzzer notification, ambient-light
  backlight control, and button acknowledgement.
- Added secure one-time device-key provisioning. Only the SHA-256 key hash is
  stored in Azure Table Storage; the plaintext key remains local to the device
  configuration.
- Corrected unread message ordering to FIFO while preserving newest-first
  ordering for normal message history.
- Validated the backend ordering tests and compiled the integrated firmware at
  66% flash and 15% RAM using the OTA-capable Minimal SPIFFS partition.
- Deployed the FIFO unread-message API update to the production Static Web App.
- Provisioned a unique key for the recipient's physical mailbox. Only the key hash
  was stored in Azure; the plaintext remained in ignored local configuration.
- Flashed the integrated firmware to the ESP32-C5 on COM4. Bootloader,
  partition table, boot application, and application image all passed hash
  verification.
- Completed the servo-free end-to-end acceptance test: Wi-Fi connected, an
  an existing unread message appeared on the TFT, the buzzer sounded,
  the VEML6030 changed backlight brightness, and the Qwiic Button acknowledged
  the message.
- Serial confirmed the acknowledged message ID and immediately displayed the
  next FIFO unread message. The production API confirmed the acknowledged ID
  was no longer unread; four unread messages remained.
- With explicit confirmation, accepted a pending contact request between the
  paired accounts. Verified reciprocal `accepted` contact records for both users
  at `2026-09-16T20:55:24.607Z`.
- Added server-authoritative photo normalization to baseline JPEG within
  216×160 using proportional fit-inside scaling, metadata rotation, no
  enlargement, and no cropping.
- Updated the web history and preview so portrait and landscape images are
  centered at their natural proportions rather than stretched to card width.
- Added a dry-run-first migration utility that creates immutable versioned
  derivatives, preserves original blobs, and records rollback URLs before
  updating message entities.
- Replaced the firmware's single-photo buffer with a two-slot LRU cache. The
  device keeps 20 message metadata records but downloads non-cached images over
  Wi-Fi and limits each JPEG to 512KB.
- Built credential-free firmware v1.2.0 at 68% flash and 21% RAM. Confirmed all
  four local provisioning values are absent. ESP image validation digest:
  `f601ca5a6bab6f3621e138c663dafb854caa8c5fc222ead3470168f3566946c7`.
- Deployed the web/API release and migrated all four existing photo records.
  The migration created four immutable derivatives, retained every original,
  and reduced stored bytes from 44,690 to 18,601 (58.4%).
- The initial Windows SWA deployment packaged only Sharp's Windows ARM64
  native binary, causing `/api/messages` to return HTTP 500. Added the Linux
  x64 Sharp/libvips runtime to the deployment bundle, redeployed, and verified
  unauthenticated HTTP 401 plus authenticated device HTTP 200 behavior.
- Uploaded and activated OTA v1.2.0. Serial observed download progress through
  100%, SHA-256 verification, reboot, version confirmation, a 2,049-byte photo
  download, and successful history loading without HTTP 500 responses.
- Physical testing confirmed photo orientation and proportions were correct and all three
  button gestures worked. Corrected the misleading control legend so BACK uses
  a double arrow with `2X BACK`, HOLD says `HOLD 1S`, and NEXT uses a single
  arrow with `1X NEXT`.
- Published OTA v1.2.1 with image digest
  `db922147a75327c38145aec42d4940ef97c57af22a4caa5a976c280bcc6c57a6`.
  Serial verified 100% download, digest verification, reboot, Wi-Fi
  reconnection, message-history loading, and version 1.2.1 confirmation.
- Connected the SparkFun 3.7V 850mAh LiPo after verifying red-to-VBAT and
  black-to-GND polarity. The yellow charger LED illuminated, USB serial showed
  no reset or brownout, and the display remained powered when USB-C was
  disconnected.
- USB testing found a real button defect: a quick tap was initially measured as
  a 270,584 ms hold because unmatched press and click queue ages were paired.
  Firmware v1.2.2 added stale-event resynchronization, reconstructed click
  timestamps, and explicit NEXT/BACK/MARK READ logs.
- Verified v1.2.2 over USB: single press measured 174 ms and moved 4/5 to 5/5;
  one-second hold measured 1,440 ms, marked the message read, and changed
  unread count from one to zero.
- A normal double press measured 707 ms, outside the original 350 ms window.
  Firmware v1.2.3 widened the window to 750 ms. Final USB validation selected
  BACK and moved 5/5 to 4/5.

### 2026-09-17 (Thu) — Public v1.2.5 Build

- Advanced the integrated firmware source to v1.2.5 with the landscape
  floating-hearts screensaver and photo prefetch before notification.
- Compiled a credential-free ESP32-C5 release using Espressif core 3.3.11 and
  the Minimal SPIFFS OTA partition.
- Build result: 1,359,133 bytes of program storage (69%) and 71,564 bytes of
  dynamic memory (21%).
- Release binary size: 1,359,280 bytes.
- Release SHA-256:
  `613b6bc3219ce74f4dc39a4564869f9929fb80bd827f8d2fd5d3a1d003bb0e51`.
- Verified the ESP32-C5 image checksum and validation hash.
- Scanned the compiled binary against all local provisioning values and
  private build-path markers; none were embedded.
- The v1.2.5 binary is build-verified but has not yet been installed on the
  physical mailbox or validated through an OTA update.

### 2026-09-18 (Fri) — SG90 Servo Wiring and Physical Validation

- Selected exposed GPIO IO1 for the SG90 signal after confirming that the
  obsolete IO18 assignment is unavailable on the SparkFun Thing Plus ESP32-C5.
- Installed the ESP32 across a mini breadboard and used shared rows instead of
  stacking DuPont connectors on the ESP32 headers.
- Physically verified orange servo signal through a purple jumper to IO1, red
  servo power through a yellow jumper to VU/VUSB, and brown servo ground
  through the shared black ground row.
- Created a serial-controlled servo smoke test using 50 Hz PWM with bounded
  1200, 1500, and 1800 us positions and an explicit detach command.
- Compiled the test at 324,384 bytes of program storage (24%) and 18,284 bytes
  of dynamic memory (5%).
- Arduino CLI upload was blocked by Windows Application Control before flash
  began. Upload through installed Python and esptool succeeded, with every
  written region passing hash verification.
- Serial confirmed stable center PWM before servo power was connected.
- Physically verified left, center, and right movement. Each movement was brief
  and controlled, followed by silence; no continuous buzzing, jitter, brownout,
  or board reset occurred.
- Added a white servo arm and widened the diagnostic with explicit 1000 and
  2000 us commands. The arm traversed clearly in both directions and settled
  quietly at each position. These are validated nominal limits, not asserted
  mechanical hard stops.
- Added a bounded manual calibration command accepting 800-2200 us in 50 us
  increments, with no automatic sweep.
- Tested each expansion step interactively and stopped for physical observation
  after every command. The servo remained quiet at every tested point.
- Clear additional travel was observed through 850 us on the left and 2150 us
  on the right. The difference at 800 us was visually uncertain, while 2200 us
  still moved farther to the right.
- Selected 850-2150 us as the conservative expanded operating range.
  The 800-2200 us tested envelope is not treated as proof of mechanical limits.
- Detached PWM and held IO1 low after testing.
- Added a reusable policy-compatible ESP32-C5 compile/upload helper and
  regression guards so the working toolchain is documented and repeatable.

### 2026-08-24 (Mon) — Evening

**Duration:** ~3 hours (21:00 – 00:00 PT)

#### Web App Development (prior checkpoints, completed before this session segment)
- Built complete SPA in `web/index.html` (~2100 lines)
- **Authentication system:** Register, login, logout, forgot-password, reset-password, change-password, email update, profile
- **JWT auth:** Custom `x-auth-token` header (SWA strips Authorization), 7-day expiry, iss/aud claims, bcrypt 12 rounds, token revocation via Table Storage blocklist
- **Password policy:** 12+ chars, upper + lower + number + special required
- **Rate limiting:** Login 5/15min, register 3/hr, messages 30/min (in-memory)
- **Messaging:** Send text + photo messages, mark read, delete, unsend, hide from sent, filter by recipient, load-more pagination
- **Photo uploads:** Base64 encoding, 2MB max, stored in Azure Blob Storage via SAS URLs (public access policy-blocked on subscription)
- **Contacts system:** Search users, send/accept/reject friend requests, remove contacts
- **Content moderation:** Azure AI Content Safety integration, severity threshold ≥2, images fail-closed, text fail-open
- **Creative Studio v2:** Rich message composer with text formatting (bold, italic, underline, strikethrough), font selection (8 fonts), font size, text color, background color, text alignment, drag-to-move text, resize handles, stickers/emoji overlay, drawing canvas, photo backgrounds, GIF search (GIPHY API placeholder)
- **i18n:** Full English/Spanish translations (~60 keys each), language selector in settings, all UI strings use `t()` function
- **Settings page:** Language selector, email field with save, password change, sign out
- **Responsive design:** Mobile-first CSS, works on phone and desktop

#### Azure Functions API
- `api/auth/index.js` (~490 lines) — 8 actions: login, register, change-password, logout, forgot-password, reset-password, update-email, profile
- `api/messages/index.js` — CRUD + Azure AI Content Safety moderation
- `api/contacts/index.js` — User search, friend request management
- `api/device/index.js` — ESP32 firmware version check with device key auth
- `api/shared/auth.js` — JWT verification middleware

#### Competitive Analysis (21:00)
- Analyzed buy.lovebox.love (Lovebox, $99–129 commercial product)
- Documented 5 feature gaps: spinning heart servo, heart-back reply button, message scheduling, message archive, template library
- Documented 3 areas where we exceed: content moderation, i18n, no subscription fees
- Stored competitive findings for physical build phase

#### Comprehensive Pentest & Audit (21:15 – 21:45)
Ran full security, functionality, i18n, and UX audit — **21 findings, all fixed:**

**Security fixes (4):**
1. XSS: replaced 3 `onclick="fn('${var}')"` injections with `data-*` + `addEventListener`
2. Reset code logging: removed 2 plaintext code logs from Azure Function output
3. Device endpoint: added `verifyDeviceKey()` authentication
4. Password observer: CSS class check instead of English text match

**i18n fixes (15):**
- Greeting, subtitle, send button, password changed, filter dropdown, empty state, status labels (read/delivered/unread), action buttons (mark read/delete/unsend/hide), load more, confirm dialogs, search results, contacts headers, force password change message
- Added 4 new keys to both EN and ES dictionaries

**UX polish (3):**
- Character counter (0/500) with live update
- Photo max size hint ("Max 2MB")
- Missing Current Password label

#### Azure Communication Services Setup (21:50 – 22:05)
- Created ACS resource: `love-letter-acs` (global, unitedstates)
- Created Email Communication Service: `love-letter-email`
- Provisioned Azure-managed email domain (auto-verified DKIM, SPF, DMARC)
- Linked email domain to ACS resource
- Configured 3 SWA app settings: ACS_ENDPOINT, ACS_KEY, ACS_FROM_EMAIL
- Sender: `DoNotReply@484a3b26-...azurecomm.net`
- **Verified end-to-end:** forgot-password → HTML email with 6-digit code arrived in ~1 minute

#### GitHub Repository Setup (22:10 – 22:25)
- Created public repo: `dbsargent-test/love-letter-mailbox`
- Switched gh CLI auth from corporate to personal (`dbsargent-test`)
- Initial commit: 24 files, 5,576 insertions
- Fixed HTTPS push with `gh auth setup-git`

#### Secrets & Proprietary Cleanup (22:25 – 22:40)
- **Fixed:** `package-lock.json` — contained corporate npm feed URLs → regenerated from public registry
- **Fixed:** Git author used corporate email → changed to personal email
- **Fixed:** Docs referenced personal accounts and corporate environment details → generalized
- **Fixed:** Journal day-of-week "Sun" → "Mon"
- Force-pushed clean history; final scan: zero proprietary hits
- Confirmed: no secrets (keys/tokens/passwords) were ever committed

#### Live Site Verification (22:45)
Ran 24 automated tests against production deployment — **22/24 passed:**
- ✅ All 5 security headers present (CSP, HSTS, X-Frame-Options, X-Content-Type-Options, X-XSS-Protection)
- ✅ Auth gates on all API endpoints
- ✅ Rate limiting triggers at 5 bad logins (429)
- ✅ No account enumeration on forgot-password
- ✅ XSS payload rejected by username regex
- ✅ HTTP → HTTPS redirect (301)
- ✅ Malformed JSON → 400 (no crash/stack trace)
- ⚠️ LOW: Logout returns 200 without auth (no security impact)
- ⚠️ LOW: Device endpoint returns 404 instead of 401 (routing gap)

---

## Budget Tracker

| Category | Planned | Actual | Delta |
|---|---|---|---|
| Hardware (2 units) | ~$92 | ~$113.97 | +$22 (850mAh battery more expensive than 400mAh) |
| Monthly hosting | ~$0.02 | $0.02 | On target |
| Time invested | — | ~5.5 hrs (afternoon: ~2.5h, evening: ~3h) | — |
| **Total project cost** | | **~$114 + time** | |

### 2026-09-19 (Sat) — ESP32-C5 Rotation, LED, and Servo Flag Build

**Hardware target:** SparkFun ESP32-C5 Thing Plus on COM4.

**Firmware outcome:**
- Flashed the current integrated mailbox firmware once and verified esptool completed region verification and hard reset.
- Rotated the TFT output 180 degrees for the physical mailbox installation by changing `display.setRotation(1)` to `display.setRotation(3)`.
- Tightened Qwiic button LED behavior so a zero-unread state forces `button.LEDoff()` and prevents blinking after the last message is read.
- Added SG90 flag servo control on IO1 using the previously validated quiet operating envelope:
  - down pulse: 850 us
  - up pulse: 2150 us
  - 50 Hz, 16-bit PWM
  - detach after 600 ms of movement hold to reduce jitter/buzzing
- Recompiled successfully and flashed the integrated rotation/LED/servo build to COM4; esptool verified all flashed regions and hard-reset the device.

**Open test reset:**
- Doug requested deleting all messages / marking all as read so the clean zero-unread behavior can be tested.
- Backend storage is Azure Table `messages` in storage account `lovelettermlbx`, resource group `love-letter-mailbox`.
- Cleanup was not completed before the session/tooling became unreliable.
- Next session should run the cleanup from `web/api` so `@azure/data-tables` resolves, set `STORAGE_ACCOUNT_NAME=lovelettermlbx` and a process-local `STORAGE_ACCOUNT_KEY` from Azure CLI, then delete all rows or mark all rows read without printing secrets.

**Validation still needed:**
- At zero unread: screen right-side up, Qwiic button LED off, servo flag down.
- On new unread message: message displays, Qwiic button LED blinks, servo flag raises.
- After marking read: Qwiic button LED turns off and servo flag lowers.
- If physical servo direction is reversed, swap `SERVO_FLAG_DOWN_US` and `SERVO_FLAG_UP_US`, compile, and flash again.

**V1 physical validation outcome:**
- After the backend message table was cleared, the device reached zero unread and the red Qwiic Button LED turned off.
- The servo-driven flag worked with the integrated firmware.
- Treat V1 as complete as of 2026-09-19.

**V2 improvement requirements captured from physical fit/use:**
- Use a larger portrait-oriented screen; selected target is the Adafruit 2.8" portrait-capable TFT with EYESPI path.
- Add a real speaker/audio playback path for MP3/songs; the current preferred architecture is ESP32-managed audio from the TFT #2090 microSD card through a MAX98357A I2S amplifier and enclosed speaker.
- Keep the physical Qwiic Button as a fallback or alternate interaction control while V2 validates heart-touch input.
- Add a Hall-effect sensor so firmware can detect/confirm when the flag has been lowered.
- Use ESP32-accessible microSD-backed media storage through the TFT #2090, not a separate audio board that owns its own SD card.
- Remove or demote the Qwiic Buzzer from the V2 hardware stack after the MAX98357A speaker path validates.
- Add a speaker acoustic chamber/vent path into the enclosure design rather than treating the speaker as a loose internal part.
- Use the ordered #1781 2200mAh cylindrical LiIon battery because the larger display, audio path, NeoPixel, haptics, and Wi-Fi bursts increase current draw.
- Rework screen and button placement because the Qwiic Button PCB interfered with the display cable.
- Redesign the servo housing; the current servo fit was wrong.
- Redesign the flag-to-servo interface; the flag did not mount correctly on the servo head.
- Add a translucent printed heart with NeoPixel glow, copper electrode, MPR121 capacitive touch, and DRV2605L haptic feedback.
- Redesign the floor/tray around ESP32 bottom-header clearance and #1781 cylindrical battery placement.

**V2 decisions to lock later:**
- Exact magnet placement for the Hall-effect sensor.
- Exact #1781 battery orientation and retention geometry.
- Final #2090 display/microSD service access after physical fit review.
- Whether capacitive heart touch replaces the Qwiic Button for the primary read/heart-back flow or remains supplemental.
- Final enclosure speaker vent/acoustic chamber geometry after speaker selection.

**OTA release lesson learned:**
- OTA publishing worked only after `FIRMWARE_SHA256` was changed from the raw
  `.bin` file SHA-256 to the ESP image validation hash reported by
  `python -m esptool image-info`.
- The firmware verifies OTA with `esp_partition_get_sha256(updatePartition)`,
  so metadata must use the `Validation hash: ... (valid)` value from esptool.
- A wrong hash type causes the mailbox to show a red OTA verification error and
  remain on the previous firmware version.
- Working v1.2.8 values:
  - raw `.bin` SHA-256:
    `ea351ce79be6f9a3a785195479c95b66aca8d531e97a2a0897f288fce59fb4d9`
  - ESP image validation hash used in `FIRMWARE_SHA256`:
    `9d291f47688472c237f85ace93b4f3c4ada9e33d87035c1b21f82e7de0ce1eaa`

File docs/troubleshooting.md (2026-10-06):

# Troubleshooting Guide

This guide primarily covers the validated V1 hardware and firmware. V2 hardware
planning is in [Mailbox V2 Build Plan](v2-build-plan.md); display, audio,
microSD, haptic, touch, and Hall-sensor troubleshooting will need to be added
after those circuits are validated.

## WiFi Issues

### Device won't connect to WiFi
1. **Check band compatibility:** The ESP32-C5 supports both 2.4GHz and 5GHz. Most routers work out of the box.
2. **Verify credentials:** SSID and password are case-sensitive. Check for trailing spaces.
3. **WPA3 networks:** The ESP32-C5 supports WPA3, but if you have issues, try WPA2 mode on your router.
4. **Hidden SSIDs:** Not recommended. Use a visible SSID.
5. **Check the TFT display:** The firmware shows WiFi status and error codes on the screen during connection.

### WiFi keeps disconnecting
1. **Signal strength:** Move the mailbox closer to the router. WiFi through walls is weaker.
2. **Power supply:** Use a quality USB-C cable and a 5V/2A charger. Cheap cables cause voltage drops during WiFi transmission.
3. **Router channel congestion:** If in an apartment, your 2.4GHz channels may be crowded. Try connecting to 5GHz instead (the C5 supports both).
4. **The firmware auto-reconnects** with exponential backoff. If WiFi drops, it will retry automatically. The hardware watchdog reboots the device after 60 seconds of unresponsiveness.

### Captive portal doesn't appear
1. Connect to the `Mailbox-Setup` WiFi network from your phone.
2. If the portal doesn't auto-open, manually navigate to `192.168.4.1` in your browser.
3. Some phones aggressively switch back to cellular. Temporarily disable mobile data.

---

## Display Issues

### Screen is blank/white
1. **Check SPI wiring:** Verify all 7 wires are connected to the correct pins (see [wiring.md](wiring.md)).
2. **Check power:** The display needs 3.3V on VCC, not 5V.
3. **Backlight pin:** Ensure BLK pin is connected to 3.3V (always on) or a GPIO pin.
4. **Wrong driver config:** The V1 firmware is configured for ST7789 240×320.
   If using a different display, update the display driver configuration. V2
   moves to the Adafruit #2090 2.8" TFT and must be validated separately.

### Screen shows garbled/wrong colors
1. **Color order:** ST7789 uses RGB, not BGR. Check `TFT_RGB_ORDER` in the firmware config.
2. **SPI speed:** If colors are garbled, try reducing SPI frequency from 40MHz to 20MHz.
3. **Offset issue:** Some 2.0" displays have a pixel offset. The firmware includes offset correction — if your display looks shifted, adjust `TFT_ROWSTART` and `TFT_COLSTART`.

### Photos look wrong
1. **Orientation:** Photos are fitted inside 216×160 with one proportional
   scale factor. Portrait remains portrait and landscape remains landscape;
   blank space around an image is expected and prevents cropping.
2. **Old photo:** Run the photo migration dry run to identify blobs created
   before server-side normalization.
3. **Memory:** The device caches at most two JPEGs and rejects downloads larger
   than 512KB. Check serial output for a rejected content length or allocation
   failure.

---

## Servo Issues

### Flag doesn't move
1. **Check wiring:** Signal wire to the correct GPIO, VCC to 5V (not 3.3V), GND to GND.
2. **Power:** Servos can draw 200-500mA. If powered from the ESP32's 3.3V pin, the servo may not have enough current. Power the servo from the USB 5V rail.
3. **Try the servo test:** Upload the basic servo sweep example from Arduino IDE to verify the servo hardware works.

### Flag jitters/buzzes
1. **Normal at rest:** SG90 servos can jitter slightly when holding position. The firmware detaches the servo after moving to eliminate jitter.
2. **Power noise:** Add a 100µF capacitor between servo VCC and GND.
3. **Signal noise:** Keep the servo signal wire away from the SPI display wires.

---

## V1 Buzzer Issues

### No sound on message arrival
1. **Check Qwiic cable:** Ensure the cable clicks into both the ESP32-C5 and the buzzer.
2. **I2C address:** The Qwiic Buzzer uses address `0x34`. Run an I2C scanner sketch to verify it's detected.
3. **Volume:** The buzzer has adjustable volume in firmware. Check the volume setting.

V2 replaces the buzzer-as-audio path with ESP32-managed SD-backed audio through
MAX98357A and an enclosed speaker. Do not use this V1 buzzer section to debug
V2 song/audio playback.

---

## Button Issues

### Button press not detected
1. **Check Qwiic cable:** Ensure the daisy-chain is complete (C5 → sensor → buzzer → button).
2. **I2C address:** The Qwiic Button uses address `0x6F`. Run an I2C scanner sketch to verify.
3. **Debounce:** The Qwiic Button has hardware debouncing built in. If it's registering double presses, check the firmware debounce timing.

---

## Azure / Backend Issues

### Messages not arriving on the device
1. **Check the web page:** Send a test message. Does the web page show "Sent!" confirmation?
2. **Check Azure:** Log into the Azure Portal → your Storage Account → Table Storage → Messages table. Is the message there?
3. **Check the device:** Open Serial Monitor in Arduino IDE (USB connected). The firmware logs every HTTP request and response. Look for HTTP error codes.
4. **HTTPS certificate:** If you see TLS/SSL errors, the ESP32's CA certificate bundle may be outdated. Update the Arduino ESP32 core.

### Web page won't load
1. **Check the URL:** Verify you're using the correct Azure Static Web App URL.
2. **Azure status:** Check [status.azure.com](https://status.azure.com) for outages.
3. **DNS:** Try the direct `*.azurestaticapps.net` URL instead of a custom domain.

### OTA update fails
1. **Check firmware binary:** Ensure the `.bin` file was compiled for the ESP32-C5, not a different board.
2. **File size:** The binary must fit in the OTA partition (~3.5MB max with 8MB flash and dual partitions).
3. **Network:** OTA downloads can take 10-30 seconds. Ensure WiFi is stable during the update.
4. **Rollback:** If a bad firmware is flashed, the watchdog timer will trigger a reboot to the previous working version within 60 seconds.

---

## Serial Monitor Debugging

To view logs:
1. Connect the mailbox to your computer via USB-C.
2. Open Arduino IDE → Tools → Serial Monitor → Set baud rate to `115200`.
3. The firmware outputs:
   - WiFi connection status
   - HTTP request/response logs
   - I2C device scan results
   - Message polling results
   - Battery voltage and percentage
   - OTA update status

---

## Factory Reset

If the device is in a bad state:
1. Hold the **BOOT** button on the ESP32-C5 while pressing **RESET**.
2. This enters bootloader mode — you can re-flash firmware via USB.
3. WiFi credentials are stored in NVS (non-volatile storage). To clear them, flash firmware with the "erase all flash" option checked in Arduino IDE.

---

## Getting Help

- **GitHub Issues:** Report bugs or request features
- **Serial logs:** Always include serial monitor output when reporting issues
- **Hardware photos:** Include photos of your wiring when reporting hardware issues

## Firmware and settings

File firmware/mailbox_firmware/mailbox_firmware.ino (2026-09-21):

#include <Adafruit_GFX.h>
#include <Adafruit_ST7789.h>
#include <ArduinoJson.h>
#include <JPEGDEC.h>
#include <Preferences.h>
#include <SPI.h>
#include <SparkFun_Qwiic_Button.h>
#include <SparkFun_Qwiic_Buzzer_Arduino_Library.h>
#include <SparkFun_VEML6030_Ambient_Light_Sensor.h>
#include <WiFi.h>
#include <Wire.h>
#include <esp_crt_bundle.h>
#include <esp_heap_caps.h>
#include <esp_http_client.h>
#include <esp_https_ota.h>
#include <esp_ota_ops.h>
#include <esp_partition.h>
#include <esp_system.h>

#ifdef EMBED_PROVISIONING_SECRETS
#include "secrets.h"
#endif

#ifdef OTA_DEMO_BOOTSTRAP
#define FIRMWARE_VERSION "1.0.0"
#else
#define FIRMWARE_VERSION "1.2.12"
#endif

#ifdef OTA_DEMO_BOOTSTRAP
constexpr bool NAVIGATION_ENABLED = false;
#else
constexpr bool NAVIGATION_ENABLED = true;
#endif

constexpr uint8_t TFT_CS = 6;
constexpr uint8_t TFT_DC = 5;
constexpr uint8_t TFT_RST = 4;
constexpr uint8_t TFT_LITE = 3;
constexpr uint8_t SERVO_PIN = 1;
constexpr uint8_t BUTTON_ADDRESS = 0x6F;
constexpr uint8_t LIGHT_ADDRESS = 0x48;
constexpr uint8_t BUZZER_ADDRESS = 0x34;
constexpr uint32_t SERVO_FREQUENCY_HZ = 50;
constexpr uint8_t SERVO_RESOLUTION_BITS = 16;
constexpr uint16_t SERVO_FLAG_DOWN_US = 850;
constexpr uint16_t SERVO_FLAG_UP_US = 2150;
constexpr unsigned long SERVO_HOLD_MS = 600;

constexpr size_t MAX_MESSAGES = 20;
constexpr size_t PHOTO_CACHE_SLOTS = 4;
constexpr size_t MAX_PHOTO_BYTES = 512UL * 1024UL;
constexpr size_t MIN_FREE_INTERNAL_HEAP_BYTES = 64UL * 1024UL;
constexpr size_t MIN_FREE_PSRAM_BYTES = 512UL * 1024UL;
constexpr int16_t PHOTO_LEFT = 8;
constexpr int16_t PHOTO_TOP = 40;
constexpr int16_t PHOTO_MAX_WIDTH = 216;
constexpr int16_t PHOTO_MAX_HEIGHT = 160;
constexpr unsigned long POLL_INTERVAL_MS = 5000;
constexpr unsigned long LIGHT_INTERVAL_MS = 1000;
constexpr unsigned long SCREENSAVER_DELAY_MS = 2UL * 60UL * 1000UL;
constexpr unsigned long SCREENSAVER_FRAME_MS = 120;
constexpr unsigned long WIFI_RETRY_MAX_MS = 60000;
constexpr uint32_t MAX_VALID_PRESS_MS = 10000;
constexpr unsigned long OTA_INITIAL_DELAY_MS = 20000;
constexpr unsigned long OTA_CHECK_INTERVAL_MS = 15UL * 60UL * 1000UL;
constexpr unsigned long STATUS_INTERVAL_MS = 60UL * 1000UL;
constexpr size_t STATUS_PAYLOAD_BYTES = 768;

Adafruit_ST7789 display(&SPI, TFT_CS, TFT_DC, TFT_RST);
QwiicButton button;
SparkFun_Ambient_Light lightSensor(LIGHT_ADDRESS);
QwiicBuzzer buzzer;
Preferences preferences;
JPEGDEC jpeg;

String wifiSsid;
String wifiPassword;
String apiBaseUrl;
String deviceKey;

struct MailMessage {
  String id;
  String sender;
  String text;
  String photoUrl;
  String displayTimestamp;
  bool read;
};

struct FirmwareRelease {
  String version;
  String url;
  String sha256;
};

struct PhotoCacheSlot {
  uint8_t *data;
  size_t size;
  String messageId;
  uint32_t lastUsedAt;
};

MailMessage messages[MAX_MESSAGES];
size_t messageCount = 0;
int currentIndex = -1;
int unreadCount = 0;
bool historyLoaded = false;
bool screensaverActive = false;
int previousLedUnreadCount = -1;
bool servoAttached = false;
bool flagRaised = false;
bool flagStateKnown = false;
bool servoDetachPending = false;
unsigned long servoDetachAt = 0;

unsigned long lastPollAt = 0;
unsigned long lastLightAt = 0;
unsigned long nextWifiAttemptAt = 0;
unsigned long wifiRetryMs = 1000;
unsigned long wifiConnectedAt = 0;
unsigned long lastOtaCheckAt = 0;
unsigned long lastUserInteractionAt = 0;
unsigned long lastScreensaverFrameAt = 0;
unsigned long lastStatusAt = 0;
uint32_t screensaverFrame = 0;
bool initialOtaCheckComplete = false;
bool bootStatusPending = true;
bool otaConfirmedStatusPending = false;
PhotoCacheSlot photoCache[PHOTO_CACHE_SLOTS] = {};
MailMessage lastDisplayedMessage;
bool hasLastDisplayedMessage = false;
String bootId;
int lastPollStatusCode = 0;
String lastErrorCode;

bool renderPhoto(const MailMessage &message);
int findOldestUnreadIndex();
void sendDeviceStatus(const char *eventName = nullptr,
                      const String &detail = "");

int drawJpegBlock(JPEGDRAW *draw) {
  display.drawRGBBitmap(draw->x, draw->y, draw->pPixels, draw->iWidth,
                        draw->iHeight);
  return 1;
}

esp_err_t collectHttpResponse(esp_http_client_event_t *event) {
  if (event->event_id == HTTP_EVENT_ON_DATA && event->user_data != nullptr) {
    String *response = static_cast<String *>(event->user_data);
    response->concat(static_cast<const char *>(event->data), event->data_len);
  }
  return ESP_OK;
}

esp_err_t addDeviceKeyHeader(esp_http_client_handle_t client) {
  return esp_http_client_set_header(client, "x-device-key",
                                    deviceKey.c_str());
}

void drawVersion() {
  display.setTextColor(ST77XX_CYAN);
  display.setTextSize(1);
  display.setCursor(4, display.height() - 10);
  display.print("v");
  display.print(FIRMWARE_VERSION);
}

void showStatus(uint16_t background, uint16_t foreground, const char *heading,
                const String &detail) {
  screensaverActive = false;
  display.fillScreen(background);
  display.setTextColor(foreground, background);
  display.setTextSize(2);
  display.setTextWrap(true);
  display.setCursor(18, 42);
  display.println(heading);
  display.setCursor(18, 92);
  display.println(detail);
  drawVersion();
}

void showIdle() {
  showStatus(ST77XX_BLACK, ST77XX_WHITE, "LOVE LETTER",
             historyLoaded ? "No messages" : "Loading messages...");
}

struct FloatingHeart {
  int16_t x;
  int16_t startY;
  uint8_t size;
  uint8_t speed;
  uint16_t color;
};

FloatingHeart floatingHearts[] = {
    {20, 214, 10, 1, 0xF81F}, {42, 152, 7, 2, 0xF9B2},
    {24, 226, 12, 1, 0xF800}, {43, 176, 8, 2, 0xFD34},
    {278, 218, 11, 1, 0xF81F}, {301, 144, 7, 2, 0xF9B2},
    {286, 228, 10, 1, 0xF800},
};

constexpr size_t FLOATING_HEART_COUNT =
    sizeof(floatingHearts) / sizeof(floatingHearts[0]);
int16_t previousHeartX[FLOATING_HEART_COUNT];
int16_t previousHeartY[FLOATING_HEART_COUNT];
bool heartFrameDrawn = false;

void drawHeart(int16_t x, int16_t y, uint8_t size, uint16_t color) {
  const int16_t radius = max(2, size / 3);
  display.fillCircle(x - radius, y - radius, radius, color);
  display.fillCircle(x + radius, y - radius, radius, color);
  display.fillTriangle(x - size / 2 - 1, y - radius, x + size / 2 + 1,
                       y - radius, x, y + size, color);
}

void eraseHeart(int16_t x, int16_t y, uint8_t size, uint16_t background) {
  int16_t left = x - size - 3;
  int16_t top = y - size - 3;
  int16_t right = x + size + 3;
  int16_t bottom = y + size + 3;
  if (left < 0) left = 0;
  if (top < 0) top = 0;
  if (right >= display.width()) right = display.width() - 1;
  if (bottom >= display.height()) bottom = display.height() - 1;
  if (right >= left && bottom >= top) {
    display.fillRect(left, top, right - left + 1, bottom - top + 1,
                     background);
  }
}

void drawScreensaverStatic() {
  constexpr uint16_t background = 0x082A;
  constexpr uint16_t panel = 0x18E3;
  display.fillScreen(background);

  display.fillRoundRect(54, 54, 212, 112, 16, panel);
  display.drawRoundRect(54, 54, 212, 112, 16, ST77XX_MAGENTA);
  drawHeart(160, 86, 20, ST77XX_RED);

  display.setTextColor(ST77XX_WHITE, panel);
  display.setTextSize(3);
  display.setTextWrap(false);
  display.setCursor(71, 112);
  display.print("LOVE LETTER");
  display.setTextSize(1);
  display.setTextColor(ST77XX_CYAN, panel);
  display.setCursor(108, 146);
  display.print(unreadCount > 0 ? "A message is waiting" : "Mailbox is ready");
}

void drawScreensaverFrame() {
  constexpr uint16_t background = 0x082A;
  if (heartFrameDrawn) {
    for (size_t i = 0; i < FLOATING_HEART_COUNT; ++i) {
      eraseHeart(previousHeartX[i], previousHeartY[i],
                 floatingHearts[i].size, background);
    }
  }

  const int16_t travelHeight = display.height() + 50;
  for (size_t i = 0; i < FLOATING_HEART_COUNT; ++i) {
    const FloatingHeart &heart = floatingHearts[i];
    const uint32_t travel =
        ((screensaverFrame * heart.speed) / 2) % travelHeight;
    int16_t y = heart.startY - static_cast<int16_t>(travel);
    while (y < -static_cast<int16_t>(heart.size)) y += travelHeight;
    const int16_t drift =
        static_cast<int16_t>((screensaverFrame / 4 + i * 3) % 9) - 4;
    const int16_t x = heart.x + drift;
    drawHeart(x, y, heart.size, heart.color);
    previousHeartX[i] = x;
    previousHeartY[i] = y;
  }

  heartFrameDrawn = true;
  drawUnreadBadge();
  drawVersion();
}

void showScreensaver() {
  screensaverActive = true;
  screensaverFrame = 0;
  heartFrameDrawn = false;
  drawScreensaverStatic();
  drawScreensaverFrame();
  lastScreensaverFrameAt = millis();
}

void drawUnreadBadge() {
  if (!NAVIGATION_ENABLED || unreadCount <= 0) return;

  const String badge = "NEW " + String(unreadCount);
  const int16_t width = badge.length() * 6 + 10;
  const int16_t left = display.width() - width - 6;
  display.fillRoundRect(left, 8, width, 18, 4, ST77XX_RED);
  display.setTextColor(ST77XX_WHITE, ST77XX_RED);
  display.setTextSize(1);
  display.setCursor(left + 5, 13);
  display.print(badge);
}

void drawReadControlBar(bool read) {
  const uint16_t background = read ? ST77XX_GREEN : ST77XX_BLUE;
  display.fillRect(0, 208, 320, 32, background);
  display.setTextColor(read ? ST77XX_BLACK : ST77XX_WHITE, background);
  display.setTextSize(2);
  if (read) {
    display.setCursor(104, 216);
    display.print("READ");
  } else {
    display.setCursor(28, 216);
    display.print("PRESS TO READ");
  }
}

void showMessage(const MailMessage &message) {
  screensaverActive = false;
  lastDisplayedMessage = message;
  hasLastDisplayedMessage = true;
  display.fillScreen(ST77XX_WHITE);

  if (NAVIGATION_ENABLED && !message.read) {
    for (int16_t inset = 0; inset < 4; ++inset) {
      display.drawRect(inset, inset, display.width() - inset * 2,
                       display.height() - inset * 2, ST77XX_RED);
    }
  }

  display.setTextColor(ST77XX_MAGENTA, ST77XX_WHITE);
  display.setTextSize(2);
  display.setTextWrap(true);
  display.setCursor(10, 8);
  display.print("FROM: ");
  display.println(message.sender);
  display.drawFastHLine(8, 34, 304, ST77XX_MAGENTA);
  drawUnreadBadge();

  const bool photoRendered =
      !message.photoUrl.isEmpty() && renderPhoto(message);

  display.setTextColor(ST77XX_BLACK, ST77XX_WHITE);
  if (photoRendered) {
    display.setTextSize(1);
    display.setCursor(232, 52);
    display.println(message.displayTimestamp);
    display.setTextSize(2);
    display.setCursor(232, 92);
    const String caption =
        message.text.length() > 42 ? message.text.substring(0, 39) + "..."
                                   : message.text;
    display.println(caption);
  } else {
    display.setTextSize(2);
    display.setCursor(12, 52);
    display.println(message.text.isEmpty() ? "[Photo unavailable]"
                                           : message.text);
    display.setTextSize(1);
    display.setCursor(12, 188);
    display.println(message.displayTimestamp);
  }

  if (NAVIGATION_ENABLED) {
    drawReadControlBar(message.read);
  } else {
    display.setTextColor(ST77XX_BLUE, ST77XX_WHITE);
    display.setTextSize(2);
    display.setCursor(12, 216);
    display.print("PRESS TO READ");
  }
}

void showError(const String &detail) {
  showStatus(ST77XX_RED, ST77XX_WHITE, "CONNECTION ERROR", detail);
}

void playTone(uint16_t durationMs, uint8_t volume) {
  buzzer.configureBuzzer(SFE_QWIIC_BUZZER_RESONANT_FREQUENCY, durationMs,
                         volume);
  buzzer.on();
}

void playNotification() {
  const uint16_t patternMs[] = {90, 90, 180, 55, 55, 55, 140};
  const uint8_t volumes[] = {
      SFE_QWIIC_BUZZER_VOLUME_LOW, SFE_QWIIC_BUZZER_VOLUME_MID,
      SFE_QWIIC_BUZZER_VOLUME_MAX, SFE_QWIIC_BUZZER_VOLUME_LOW,
      SFE_QWIIC_BUZZER_VOLUME_LOW, SFE_QWIIC_BUZZER_VOLUME_MID,
      SFE_QWIIC_BUZZER_VOLUME_MAX,
  };
  for (size_t i = 0; i < sizeof(patternMs) / sizeof(patternMs[0]); ++i) {
    playTone(patternMs[i], volumes[i]);
    delay(patternMs[i] + 35);
  }
}

uint32_t pulseToDuty(uint16_t pulseUs) {
  constexpr uint32_t PERIOD_US = 20000;
  constexpr uint32_t MAX_DUTY = (1UL << SERVO_RESOLUTION_BITS) - 1;
  return (static_cast<uint32_t>(pulseUs) * MAX_DUTY) / PERIOD_US;
}

bool attachServo() {
  if (servoAttached) return true;
  pinMode(SERVO_PIN, OUTPUT);
  digitalWrite(SERVO_PIN, LOW);
  servoAttached =
      ledcAttach(SERVO_PIN, SERVO_FREQUENCY_HZ, SERVO_RESOLUTION_BITS);
  if (!servoAttached) {
    Serial.println("Servo PWM setup failed on IO1.");
  }
  return servoAttached;
}

void detachServo() {
  if (servoAttached) {
    ledcDetach(SERVO_PIN);
    servoAttached = false;
  }
  pinMode(SERVO_PIN, OUTPUT);
  digitalWrite(SERVO_PIN, LOW);
  servoDetachPending = false;
}

void moveFlag(bool raise) {
  if (!attachServo()) return;
  const uint16_t pulse = raise ? SERVO_FLAG_UP_US : SERVO_FLAG_DOWN_US;
  ledcWrite(SERVO_PIN, pulseToDuty(pulse));
  flagRaised = raise;
  flagStateKnown = true;
  servoDetachPending = true;
  servoDetachAt = millis() + SERVO_HOLD_MS;
  Serial.printf("Flag servo: %s (%u us)\n", raise ? "UP" : "DOWN", pulse);
}

void updateFlagState() {
  const bool shouldRaise = unreadCount > 0;
  if (!flagStateKnown || shouldRaise != flagRaised) {
    moveFlag(shouldRaise);
  }
}

void maintainServo() {
  if (servoDetachPending &&
      static_cast<long>(millis() - servoDetachAt) >= 0) {
    detachServo();
  }
}

uint8_t brightnessForLux(long lux) {
  if (lux < 5) return 25;
  if (lux < 50) return 60;
  if (lux < 250) return 120;
  return 220;
}

bool wifiConfigured() {
  return !wifiSsid.isEmpty() && !wifiPassword.isEmpty() &&
         !apiBaseUrl.isEmpty() && !deviceKey.isEmpty();
}

void loadConfiguration() {
  preferences.begin("mailbox", false);
#ifdef EMBED_PROVISIONING_SECRETS
  preferences.putString("wifi_ssid", WIFI_SSID);
  preferences.putString("wifi_pass", WIFI_PASSWORD);
  preferences.putString("api_url", API_BASE_URL);
  preferences.putString("device_key", DEVICE_KEY);
#endif
  wifiSsid = preferences.getString("wifi_ssid", "");
  wifiPassword = preferences.getString("wifi_pass", "");
  apiBaseUrl = preferences.getString("api_url", "");
  deviceKey = preferences.getString("device_key", "");
  preferences.end();
}

void maintainWifi() {
  static bool wasConnected = false;
  const bool connected = WiFi.status() == WL_CONNECTED;

  if (connected) {
    wifiRetryMs = 1000;
    if (!wasConnected) {
      wifiConnectedAt = millis();
      Serial.print("WiFi connected. IP: ");
      Serial.println(WiFi.localIP());
    }
    wasConnected = true;
    return;
  }

  wasConnected = false;
  const unsigned long now = millis();
  if (now < nextWifiAttemptAt || !wifiConfigured()) return;

  Serial.printf("Connecting to WiFi SSID '%s'...\n", wifiSsid.c_str());
  WiFi.disconnect();
  WiFi.begin(wifiSsid.c_str(), wifiPassword.c_str());
  nextWifiAttemptAt = now + wifiRetryMs;
  wifiRetryMs = min(wifiRetryMs * 2, WIFI_RETRY_MAX_MS);
}

bool performRequest(const String &url, esp_http_client_method_t method,
                    String &response, int &statusCode,
                    const char *payload = nullptr, size_t payloadLength = 0) {
  esp_http_client_config_t config = {};
  config.url = url.c_str();
  config.event_handler = collectHttpResponse;
  config.user_data = &response;
  config.crt_bundle_attach = esp_crt_bundle_attach;
  config.timeout_ms = 10000;

  esp_http_client_handle_t client = esp_http_client_init(&config);
  if (client == nullptr) {
    Serial.println("Failed to initialize HTTPS client.");
    return false;
  }

  esp_http_client_set_method(client, method);
  esp_http_client_set_header(client, "x-device-key", deviceKey.c_str());
  esp_http_client_set_header(client, "Accept", "application/json");
  if (method == HTTP_METHOD_PATCH || method == HTTP_METHOD_POST) {
    esp_http_client_set_header(client, "Content-Type", "application/json");
    if (payload != nullptr && payloadLength > 0) {
      esp_http_client_set_post_field(client, payload, payloadLength);
    } else {
      esp_http_client_set_post_field(client, "{}", 2);
    }
  }

  const esp_err_t result = esp_http_client_perform(client);
  statusCode = esp_http_client_get_status_code(client);
  esp_http_client_cleanup(client);

  if (result != ESP_OK) {
    Serial.printf("HTTPS request failed: %s\n", esp_err_to_name(result));
    return false;
  }
  return true;
}

String resetReasonName() {
  switch (esp_reset_reason()) {
    case ESP_RST_POWERON:
      return "poweron";
    case ESP_RST_EXT:
      return "external";
    case ESP_RST_SW:
      return "software";
    case ESP_RST_PANIC:
      return "panic";
    case ESP_RST_INT_WDT:
      return "interrupt_watchdog";
    case ESP_RST_TASK_WDT:
      return "task_watchdog";
    case ESP_RST_WDT:
      return "watchdog";
    case ESP_RST_DEEPSLEEP:
      return "deepsleep";
    case ESP_RST_BROWNOUT:
      return "brownout";
    case ESP_RST_SDIO:
      return "sdio";
    default:
      return "unknown";
  }
}

String displayStateName() {
  if (screensaverActive) return "screensaver";
  if (currentIndex >= 0 && messageCount > 0) return "message";
  if (historyLoaded) return "idle";
  return "startup";
}

String currentMessageId() {
  if (currentIndex >= 0 && currentIndex < static_cast<int>(messageCount)) {
    return messages[currentIndex].id;
  }
  if (hasLastDisplayedMessage) return lastDisplayedMessage.id;
  return "";
}

void sendDeviceStatus(const char *eventName, const String &detail) {
  if (WiFi.status() != WL_CONNECTED || !wifiConfigured()) return;

  JsonDocument document;
  document["firmwareVersion"] = FIRMWARE_VERSION;
  document["bootId"] = bootId;
  document["uptimeMs"] = millis();
  document["resetReason"] = resetReasonName();
  document["wifiRssi"] = WiFi.RSSI();
  document["freeHeap"] = heap_caps_get_free_size(MALLOC_CAP_INTERNAL);
  document["minFreeHeap"] = heap_caps_get_minimum_free_size(MALLOC_CAP_INTERNAL);
  document["freePsram"] = heap_caps_get_free_size(MALLOC_CAP_SPIRAM);
  document["minFreePsram"] = heap_caps_get_minimum_free_size(MALLOC_CAP_SPIRAM);
  document["displayState"] = displayStateName();
  document["currentMessageId"] = currentMessageId();
  document["unreadCount"] = unreadCount;
  document["flagState"] = flagRaised ? "raised" : "lowered";
  document["buttonLedState"] = previousLedUnreadCount > 0 ? "active" : "off";
  document["lastPollStatus"] = lastPollStatusCode;
  document["lastErrorCode"] = lastErrorCode;
  if (eventName != nullptr && eventName[0] != '\0') {
    document["event"] = eventName;
    document["detail"] = detail;
  }

  char payload[STATUS_PAYLOAD_BYTES];
  const size_t payloadLength = serializeJson(document, payload, sizeof(payload));
  if (payloadLength == 0 || payloadLength >= sizeof(payload)) {
    Serial.println("Device status payload serialization failed.");
    return;
  }

  String response;
  int statusCode = 0;
  const String url = apiBaseUrl + "/api/device/status";
  if (!performRequest(url, HTTP_METHOD_POST, response, statusCode, payload,
                      payloadLength) ||
      statusCode != 200) {
    Serial.printf("Device status POST failed: HTTP %d %s\n", statusCode,
                  response.c_str());
    return;
  }

  Serial.printf("Device status sent%s%s\n", eventName ? ": " : "",
                eventName ? eventName : "");
}

void releasePhotoCacheSlot(PhotoCacheSlot &slot) {
  if (slot.data != nullptr) {
    heap_caps_free(slot.data);
    slot.data = nullptr;
  }
  slot.size = 0;
  slot.messageId = "";
  slot.lastUsedAt = 0;
}

PhotoCacheSlot *findPhotoCacheSlot(const String &messageId) {
  for (size_t i = 0; i < PHOTO_CACHE_SLOTS; ++i) {
    if (photoCache[i].data != nullptr &&
        photoCache[i].messageId == messageId) {
      photoCache[i].lastUsedAt = millis();
      return &photoCache[i];
    }
  }
  return nullptr;
}

void releasePhotoForMessage(const String &messageId) {
  PhotoCacheSlot *slot = findPhotoCacheSlot(messageId);
  if (slot != nullptr) releasePhotoCacheSlot(*slot);
}

PhotoCacheSlot &selectPhotoCacheSlot() {
  for (size_t i = 0; i < PHOTO_CACHE_SLOTS; ++i) {
    if (photoCache[i].data == nullptr) return photoCache[i];
  }

  const uint32_t now = millis();
  size_t oldestIndex = 0;
  uint32_t oldestAge = now - photoCache[0].lastUsedAt;
  for (size_t i = 1; i < PHOTO_CACHE_SLOTS; ++i) {
    const uint32_t age = now - photoCache[i].lastUsedAt;
    if (age > oldestAge) {
      oldestAge = age;
      oldestIndex = i;
    }
  }
  return photoCache[oldestIndex];
}
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
void loop() {
  maintainWifi();
  handleButton();
  updateButtonLed();
  updateFlagState();
  maintainServo();

  const unsigned long now = millis();
  if (now - lastLightAt >= LIGHT_INTERVAL_MS) {
    lastLightAt = now;
    ledcWrite(TFT_LITE, brightnessForLux(lightSensor.readLight()));
  }

  if (now - lastPollAt >= POLL_INTERVAL_MS) {
    lastPollAt = now;
    pollMessages();
  }

  if (WiFi.status() == WL_CONNECTED) {
    if (otaConfirmedStatusPending) {
      otaConfirmedStatusPending = false;
      lastStatusAt = now;
      sendDeviceStatus("ota_confirmed", FIRMWARE_VERSION);
    } else if (bootStatusPending) {
      bootStatusPending = false;
      lastStatusAt = now;
      sendDeviceStatus("boot", resetReasonName());
    } else if (now - lastStatusAt >= STATUS_INTERVAL_MS) {
      lastStatusAt = now;
      sendDeviceStatus("heartbeat", "");
    }
  }

  updateScreensaver();

  if (WiFi.status() == WL_CONNECTED && wifiConnectedAt > 0) {
    if (!initialOtaCheckComplete &&
        now - wifiConnectedAt >= OTA_INITIAL_DELAY_MS) {
      initialOtaCheckComplete = true;
      lastOtaCheckAt = now;
      checkForOtaUpdate();
    } else if (initialOtaCheckComplete &&
               now - lastOtaCheckAt >= OTA_CHECK_INTERVAL_MS) {
      lastOtaCheckAt = now;
      checkForOtaUpdate();
    }
  }

  delay(20);
}

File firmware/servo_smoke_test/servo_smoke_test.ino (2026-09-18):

#include <Arduino.h>

constexpr uint8_t SERVO_PIN = 1;
constexpr uint32_t SERVO_FREQUENCY_HZ = 50;
constexpr uint8_t SERVO_RESOLUTION_BITS = 16;
constexpr uint16_t SERVO_WIDE_LEFT_US = 1000;
constexpr uint16_t SERVO_LEFT_US = 1200;
constexpr uint16_t SERVO_CENTER_US = 1500;
constexpr uint16_t SERVO_RIGHT_US = 1800;
constexpr uint16_t SERVO_WIDE_RIGHT_US = 2000;
constexpr uint16_t SERVO_CALIBRATION_MIN_US = 800;
constexpr uint16_t SERVO_CALIBRATION_MAX_US = 2200;
constexpr uint16_t SERVO_CALIBRATION_STEP_US = 50;

bool servoAttached = false;

uint32_t pulseToDuty(uint16_t pulseUs) {
  constexpr uint32_t PERIOD_US = 20000;
  constexpr uint32_t MAX_DUTY = (1UL << SERVO_RESOLUTION_BITS) - 1;
  return (static_cast<uint32_t>(pulseUs) * MAX_DUTY) / PERIOD_US;
}

bool attachServo() {
  if (servoAttached) return true;
  pinMode(SERVO_PIN, OUTPUT);
  digitalWrite(SERVO_PIN, LOW);
  servoAttached =
      ledcAttach(SERVO_PIN, SERVO_FREQUENCY_HZ, SERVO_RESOLUTION_BITS);
  return servoAttached;
}

void writePosition(uint16_t pulseUs, const char *label) {
  if (!attachServo()) {
    Serial.println("ERROR: Unable to attach servo PWM on IO1.");
    return;
  }
  ledcWrite(SERVO_PIN, pulseToDuty(pulseUs));
  Serial.printf("Servo position: %s (%u us)\n", label, pulseUs);
}

void detachServo() {
  if (servoAttached) {
    ledcDetach(SERVO_PIN);
    servoAttached = false;
  }
  pinMode(SERVO_PIN, OUTPUT);
  digitalWrite(SERVO_PIN, LOW);
  Serial.println("Servo signal detached and IO1 held LOW.");
}

void printCommands() {
  Serial.println("Commands:");
  Serial.println("  1 = left test position (1200 us)");
  Serial.println("  2 = center position (1500 us)");
  Serial.println("  3 = right test position (1800 us)");
  Serial.println("  4 = wide left test position (1000 us)");
  Serial.println("  5 = wide right test position (2000 us)");
  Serial.println("  p#### = calibration pulse, 800-2200 us in 50 us steps");
  Serial.println("  x = detach signal and hold IO1 LOW");
}

void setup() {
  Serial.begin(115200);
  Serial.setTimeout(250);
  delay(1500);

  Serial.println("SG90 servo smoke test on IO1.");
  writePosition(SERVO_CENTER_US, "CENTER");
  Serial.println(
      "PWM is stable at center. Connect servo VUSB power only after this line.");
  printCommands();
}

void loop() {
  if (!Serial.available()) return;

  const char command = static_cast<char>(Serial.read());
  switch (command) {
    case '1':
      writePosition(SERVO_LEFT_US, "LEFT");
      break;
    case '2':
      writePosition(SERVO_CENTER_US, "CENTER");
      break;
    case '3':
      writePosition(SERVO_RIGHT_US, "RIGHT");
      break;
    case '4':
      writePosition(SERVO_WIDE_LEFT_US, "WIDE LEFT");
      break;
    case '5':
      writePosition(SERVO_WIDE_RIGHT_US, "WIDE RIGHT");
      break;
    case 'p':
    case 'P': {
      const long pulseUs = Serial.parseInt();
      if (pulseUs < SERVO_CALIBRATION_MIN_US ||
          pulseUs > SERVO_CALIBRATION_MAX_US ||
          pulseUs % SERVO_CALIBRATION_STEP_US != 0) {
        Serial.println(
            "ERROR: Calibration pulse must be 800-2200 us in 50 us steps.");
        break;
      }
      writePosition(static_cast<uint16_t>(pulseUs), "CALIBRATION");
      break;
    }
    case 'x':
    case 'X':
      detachServo();
      break;
    case '\r':
    case '\n':
      break;
    default:
      Serial.printf("Unknown command: %c\n", command);
      printCommands();
      break;
  }
}

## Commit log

2026-08-25 Initial commit: Love Letter Mailbox web app
    Complete SPA with Azure Static Web Apps backend:
    - Auth (login, register, forgot/reset password, email verification via ACS)
    - Messaging with photo attachments and content moderation (Azure AI)
    - Contact management (search, request, accept/reject)
    - Creative Studio v2 (drawing, stickers, text, fonts, GIF cards)
    - i18n (English + Spanish)
    - Security hardened (XSS prevention, rate limiting, audit logging, CSP)
    - ESP32 device API with authenticated firmware check
    Copilot-Session: b829466c-9da5-4955-b733-d4819097b0ad
2026-08-31 Add enclosure v1: caliper-verified OpenSCAD design with 6 STL exports
    - Parametric mailbox enclosure (110x80x58mm) with snap-fit assembly
    - 6 parts: body, door, door_frame, flag, tray, sensor_bracket
    - All dimensions caliper-verified against real components
    - Qwiic Button mounted on door panel with PCB cradle
    - Component tray: ESP32 right, Battery/EYESPI/Buzzer stacked left
    - Sensor bracket mounts on roof (v2: redesign for light path)
    - All PLA: White (body/door/bracket), Black (frame), Green (flag), Gray (tray)
    Copilot-Session: 3610426a-0231-4efc-95c5-f2b2c280a3b4
    [mailbox V1.3mf, mailbox.scad, mailbox_body.stl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]
2026-09-18 Publish firmware v1.2.5 and current project updates
    Add the integrated ESP32-C5 firmware, API hardening, photo normalization, regression tests, updated documentation, and enclosure v2 printable assets. Exclude local credentials, migration reports, gen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
    Copilot-Session: 8409a03b-758f-4e9c-aabb-551e600748ff
    [mailbox.scad, mailbox_v2_coupon_sg90_horn.stl, mailbox_v2_coupon_snap_floor.stl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]
2026-09-18 Document and validate SG90 servo wiring
    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
2026-09-18 Validate wider SG90 servo range
    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
2026-09-18 Add supervised SG90 range calibration
    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
2026-09-19 Release mailbox firmware queue mode updates
    Document the working OTA validation-hash process and add regression guards for the queue-mode button behavior, screensaver startup, and post-read display state.
2026-09-21 Add mailbox device heartbeat telemetry
2026-09-21 Parse device status JSON bodies
2026-09-21 Handle raw device status bodies
2026-09-21 Fix heartbeat JSON POST buffer
    [mailbox_firmware.ino]
